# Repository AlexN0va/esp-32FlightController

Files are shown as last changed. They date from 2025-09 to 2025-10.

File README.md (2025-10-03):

# ESP32-S3 Drone Project 🚁

An ultra-compact, low-cost quadcopter platform powered by the **ESP32-S3 microcontroller**.
This project integrates **wireless control, power management, and a full sensing suite** into a **single PCB design**, achieving a robust and manufacturable drone for under **$50 per unit ($32.01)**.

---

##  Features

### Core Controller

* **ESP32-S3** microcontroller with **WiFi + Bluetooth** for remote control and telemetry.
* **USB-C** interface for programming and charging.
* **Status LEDs** for debugging and state indication.

### 📡 Wireless Control

* Built-in **WiFi/Bluetooth** communication.
* Custom real-time control protocol.

### Power Management

* **350mAh single-cell LiPo battery (1S)**.
* **Integrated charging circuitry** on PCB.
* **TPS5642 buck converter** regulates 3.7–4.2V battery input down to 3.3V.
* **Battery monitoring system** with undervoltage protection for safe operation.

### Motor Control

* **Four brushed DC motors** driven via **low RDS-on MOSFETs**.
* **PWM control** for smooth throttle response.
* Optimized **flyback diode placement** for reduced EMI and motor protection.

### Sensing Suite

* **BMP390 Barometer** – altitude measurements with ±0.5m accuracy.
* **ICM-42670-P 6-axis IMU** – accelerometer + gyroscope.
* **SPI communication** for fast and reliable sensor data exchange.
* **Sensor fusion algorithm** for stabilization.

### Compact Design

* **3.2” x 3.2” arms** with a **central PCB hub**.
* **Single-board design** for simplified manufacturing and assembly.
* **Integrated charging system** – no external circuitry required.

---

## Achieved Milestones

* Full system integration on a **single PCB**.
* Reliable flight stabilization using **sensor fusion**.
* Cost-effective design: **$32.01 BOM cost (under $50 target)**.

---

## Images 

### Final Drone Assembly & PCB Layout & Schematic

https://docs.google.com/presentation/d/1kFseCS2gQPJ-yQV6XV5w5bWRBxy75CzPxFKIJwM_sh4/edit?usp=sharing

---

## 📂 Repository Structure

```bash
├── firmware/          # ESP32-S3 firmware for flight control and wireless comm
├── hardware/          # PCB design files, schematics, layouts
├── docs/              # Images, diagrams, and documentation
└── README.md          # Project overview
```

---

## 🚀 Future Work

* Improve flight algorithms with advanced sensor fusion (Kalman filter / complementary filter).
* Add support for brushless motors + ESCs.
* Expand telemetry features (battery %, orientation, altitude streaming).
* Enhance custom wireless control protocol for lower latency.

---

Would you like me to also **add a wiring diagram block** (using ASCII art or schematic-style markdown) to visually show how the ESP32, sensors, power, and motors connect, so people can understand it even without opening the schematic files?

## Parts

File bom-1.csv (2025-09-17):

Designator | Footprint | Quantity | Value | LCSC Part #
3.3V | TestPoint_Loop_D1.80mm_Drill1.0mm_Beaded | 1 | +3.3V
BOOT, EN | SW_SKRPACE010 | 2 | SKRPACE010
C21, C23 | 0201 | 2 | 100nF
C22, C29 | 0201 | 2 | 10uF
C24 | 0201 | 1 | 10nF
C25, C31, C32, C4, C6, C7 | 0201 | 6 | 0.1uF
C26 | 0201 | 1 | 2.2uF
C27 | 0201 | 1 | 47uF
C28, C30 | 0201 | 2 | 1uF
C5 | 0201 | 1 | 22uF
CR1, CR2, CR3, CR4 | CFP3_SOD123W_NEX | 4 | PMEG10020ELRX
D1 | LED_Cree-PLCC4_3.2x2.8mm_CCW | 1 | CLV1L-FKB
D3 | SMF50AQTP | 1 | SMF5.0AQ-TP
D8 | 0603 | 1 | LED
IC2 | SOT50P160X60-6N | 1 | TPS564252DRLR
J7 | GCT_USB4105-GF-A | 1 | USB4105-GF-A
L2 | INDC2520X100N | 1 | 3.3uH
MOSFET1, MOSFET2, MOSFET3, MOSFET4 | SOT-23_MCC | 4 | SI2302-TP
MOTOR1 | Molex_CLIK-Mate_502382-0270_1x02-1MP_P1.25mm_Vertical | 1 | Motor1
MOTOR2 | Molex_CLIK-Mate_502382-0270_1x02-1MP_P1.25mm_Vertical | 1 | Motor2
MOTOR3 | Molex_CLIK-Mate_502382-0270_1x02-1MP_P1.25mm_Vertical | 1 | Motor3
MOTOR4 | Molex_CLIK-Mate_502382-0270_1x02-1MP_P1.25mm_Vertical | 1 | Motor4
MT1 | XDCR_ICM-42670-P | 1 | ICM-42670-P
R1, R13, R8 | 0201 | 3 | 120
R10, R11, R12, R19, R2, R21, R22, R6, R7, R9 | 0201 | 10 | 10k
R20 | 0201 | 1 | 45.3k
R23 | 0201 | 1 | 2k
R24 | 0201 | 1 | 13k
R25 | 0201 | 1 | 18k
R26, R27 | 0201 | 2 | 5k1
R3 | 0201 | 1 | 100k
R4 | 0201 | 1 | 50k
R5 | 0201 | 1 | 220R
TP3 | TestPoint_Loop_D1.80mm_Drill1.0mm_Beaded | 1 | GND
U1 | ESP32-S3-WROOM-1 | 1 | ESP32-S3-WROOM-1
U2 | SOT-666 | 1 | USBLC6-2P6
U4 | WSON10_DLH_TEX | 1 | BQ25185DLHR
U7 | 10LGA_2X2X0p75_BOS | 1 | BMP390
VBAT | CONN_S2B-PH-K-S_JST | 1 | S2B-PH-K-SLFSN
VBUS | TestPoint_Loop_D1.80mm_Drill1.0mm_Beaded | 1 | VBUS

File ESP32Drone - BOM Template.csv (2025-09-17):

Partner 1 Name:Richard Gomez | Partner 1 Email:20177421Rgomez@berkeley.edu | Partner 2 Name: Emmanuel Matute | Partner 2 Email: lemz4@berkeley.edu | Partner 3 Name: | Partner 3 Email:
Instructions
Fill in the cells with the YELLOW highlight. Do not edit red cells. WE WILL ADJUST THE MULTIPLIER TO ACCOUNT FOR MULTIPLE BOARDS, YOU SHOULD NOT. Fill out the Digi-Key part # OR the Mouser Part #, DO NOT fill out both. Choose the cheapest distributor that has the part in stock. If the part is not in stock by the time we order parts, there is a risk that we will not purchase it. For any approved Amazon or Adafruit parts, leave Digi-key and Mouser Part# columns blank like the example. For approved Amazon parts, put the ASIN (under the Product Information Section) for Manufacturer Part # in the format "Amazon - ##########". For approved Adafruit parts, put the Product ID for Manufacturer Part # in the format "Adafruit - ####". |  |  |  |  |  |  |  |  |  |  | Total Price for Project
 |  |  |  |  |  |  |  |  |  |  | #VALUE!
Qty (for 1 board) | Manufacturer Part # | Digi-key Part#/SKU | Mouser Part#/SKU | Price/unit ($) | Purchase URL | Reference Designator | Description (include component value if applicable) | Datasheet Link | Multiple | Total Qty | Total Price/part ($)
Sensors/Motor
4 | 739 | 36-739-ND |  | 0.28 | Link | rubber for 716
4 | 108990001 | 1597-1202-ND |  | 1.95 | Link | 716 Motors |  | Link |  | 4
1 | ICM-42670-P | 1428-ICM-42670-PCT-ND |  | 3.66 | Link | (Main Sensor) Accelerometer, Gyroscope, Temperature, 6 Axis Sensor |  | Link |  | 0 | 0
4 | SI2302-TP | SI2302-TPMSTR-ND |  | 0.45 | Link | N-Channel Mosfet |  | Link |  | 0 | 0
1 | BMP390 | 828-BMP390CT-ND |  | 3.15 | Link | Barometer ( Digital Pressure Sensor) |  | Link |  | 0 | 0
4 | PMEG10020ELRX | 1727-2396-2-ND |  | 0.26 | Link |  | flyback diode | Link |  | 0 | 0
1 | C0603C222K3RACTU | 399-C0603C222K3RACTUTR-ND |  | 0.1 | Link | 2.2 µFCeramic Capacitor X7R |  |  |  | 0 | 0
4 | RK73H1JTTD1002F | 2019-RK73H1JTTD1002FTR-ND |  | $0.10 | Link |  | Mosfet pull-downs 10k | Link |  | 0 | $0.00
1 | CC0603KRX7R8BB103 | 311-1360-2-ND |  | $0.10 | Link | 10nF capacitor
3 | CC0603KRX7R7BB104 | 311-1088-2-ND |  | $0.08 | Link |  | capacitor 100nF decoupling | Link
Power Section: |  |  |  |  |  |  |  |  |  | #VALUE! | #VALUE!
1 | TPS564252DRLR | 296-TPS564252DRLRTR-ND |  | $0.46 | Link |  | Buck converter | Link |  | 0 | $0.00
1 | 497-5026-2-ND | USBLC6-2P6 |  | $0.44 | Link |  | ESD protection for USB | Link |  | 0 | $0.00
1 | USB4105-GF-A | 2073-USB4105-GF-ATR-ND |  | $0.78 | Link |  | USB-C Receptacle | Link |  | 0 | $0.00
1 | SMF5.0AQ-TP | 353-SMF5.0AQ-TPTR-ND |  | $0.11 | Link |  | TVS protection for VBUS | Link |  | 0 | $0.00
2 | RK73H1JTTD1002F | 2019-RK73H1JTTD1002FTR-ND |  | $0.10 | Link |  | Feedback resistor 10k and PG indicator |  |  | 0 | $0.00
1 | RMCF0603FT45K3 | RMCF0603FT45K3TR-ND |  | $0.10 | Link |  | Feedback resistor 45.3k |  |  | 0 | $0.00
5 | CC0603KRX7R7BB104 | 311-1088-2-ND |  | $0.08 | Link |  | capacitor 100nF |  |  | 0 | $0.00
4 | CL10A106MP8NNNC | 1276-1871-2-ND |  | $0.09 | Link |  | cap 10uF |  |  | 0 | $0.00
1 | GRM188R60J476ME01D | 490-GRM188R60J476ME01DTR-ND |  | $0.36 | Link |  | cap 47uF |  |  | 0 | $0.00
2 | RC0603FR-075K1L | 311-5.10KHRTR-ND |  | $0.10 | Link |  | USB CC resistors 5.1k |  |  | 0 | $0.00
1 | SRP3212-3R3M | 118-SRP3212-3R3MTR-ND |  | $0.18 | Link |  | Inductor |  |  | 0 | $0.00
1 | RC0603FR-07210RL | 311-210HRCT-ND |  | $0.10 | Link |  | 210 ohm resistor
1 | LTST-C190GKT | 160-1183-2-ND |  | $0.14 | Link |  | green led | Link
Lipo-Charger
1 | BQ25185DLHR | 296-BQ25185DLHRTR-ND |  | $1.80 | Link |  | lipo batt. charger 1A | Link |  | 0 | $0.00
2 | CL10B105KA8NNNC | 1276-1184-2-ND |  | $0.06 | Link |  | 1uf cap |  |  | 0 | $0.00
1 | CL31B106KAHNNNE | 1276-1804-2-ND |  | $0.12 | Link |  | 10uf cap
3 | RK73H1JTTD1002F | 2019-RK73H1JTTD1002FTR-ND |  | $0.10 | Link |  | pullups/pulldowns | Link
1 | RK73H1JTTD1302F | 2019-RK73H1JTTD1302FTR-ND |  | $0.10 | Link |  | ILIM resistor 13k | Link
1 | AC0603FR-0718KL | YAG3570TR-ND |  | $0.10 | Link |  | ILIM resistor 18k | Link
1 | ERA-3AEB202V | P2.0KDBTR-ND |  | $0.10 | Link |  | 2k ISET resistor | Link
MCU: |  |  |  |  |  |  |  |  |  | #VALUE! | #VALUE!
 | ESP32-S3-WROOM-1-N8 | ESP32-S3-WROOM-1-N8 |  | 5.49 | Link |  | esp32 |  |  | 0 | 0
3 | CC0603KRX7R7BB104 | 311-1088-2-ND |  | $0.08 | Link |  | capacitor 100nF decoupling/switch debounce |  |  | 0 | $0.00
1 | CL10A226MP8NUNE | CL10A226MP8NUNE |  | $0.10 | Link |  | 22uF |  |  | 0 | $0.00
2 | SKRPACE010 | 4809-SKRPACE010TR-ND |  | $0.11 | Link |  | switch for en pin and boot |  |  | 0 | $0.00
1 | ERJ-3EKF1003V | P100KHTR-ND |  | $0.10 | Link |  | 100k for voltage sense |  |  | 0 | $0.00
1 | RT0603BRD0750KL | 13-RT0603BRD0750KLTR-ND |  | $0.14 | Link |  | 50k for voltage sense |  |  | 0 | $0.00
2 | RK73H1JTTD1002F | 2019-RK73H1JTTD1002FTR-ND |  | $0.10 | Link |  | 10k pullup for en and boot |  |  | 0 | $0.00
1 | CLV1L-FKB-CJ1N1E1BB7B3B3 | 90-CLV1L-FKB-CJ1N1E1BB7B3B3TR-ND |  | $0.43 | Link |  | debug LEDS, status indication etc |  |  | 0 | $0.00
3 | ERA-3AEB121V | P120DBTR-ND |  | $0.10 | Link |  | Led resistor 120ohm |  |  | 0 | $0.00
Battery |  |  |  |  |  |  |  |  |  | #VALUE! | #VALUE!
1 |  |  |  |  |  |  |  |  |  | 0 | 0

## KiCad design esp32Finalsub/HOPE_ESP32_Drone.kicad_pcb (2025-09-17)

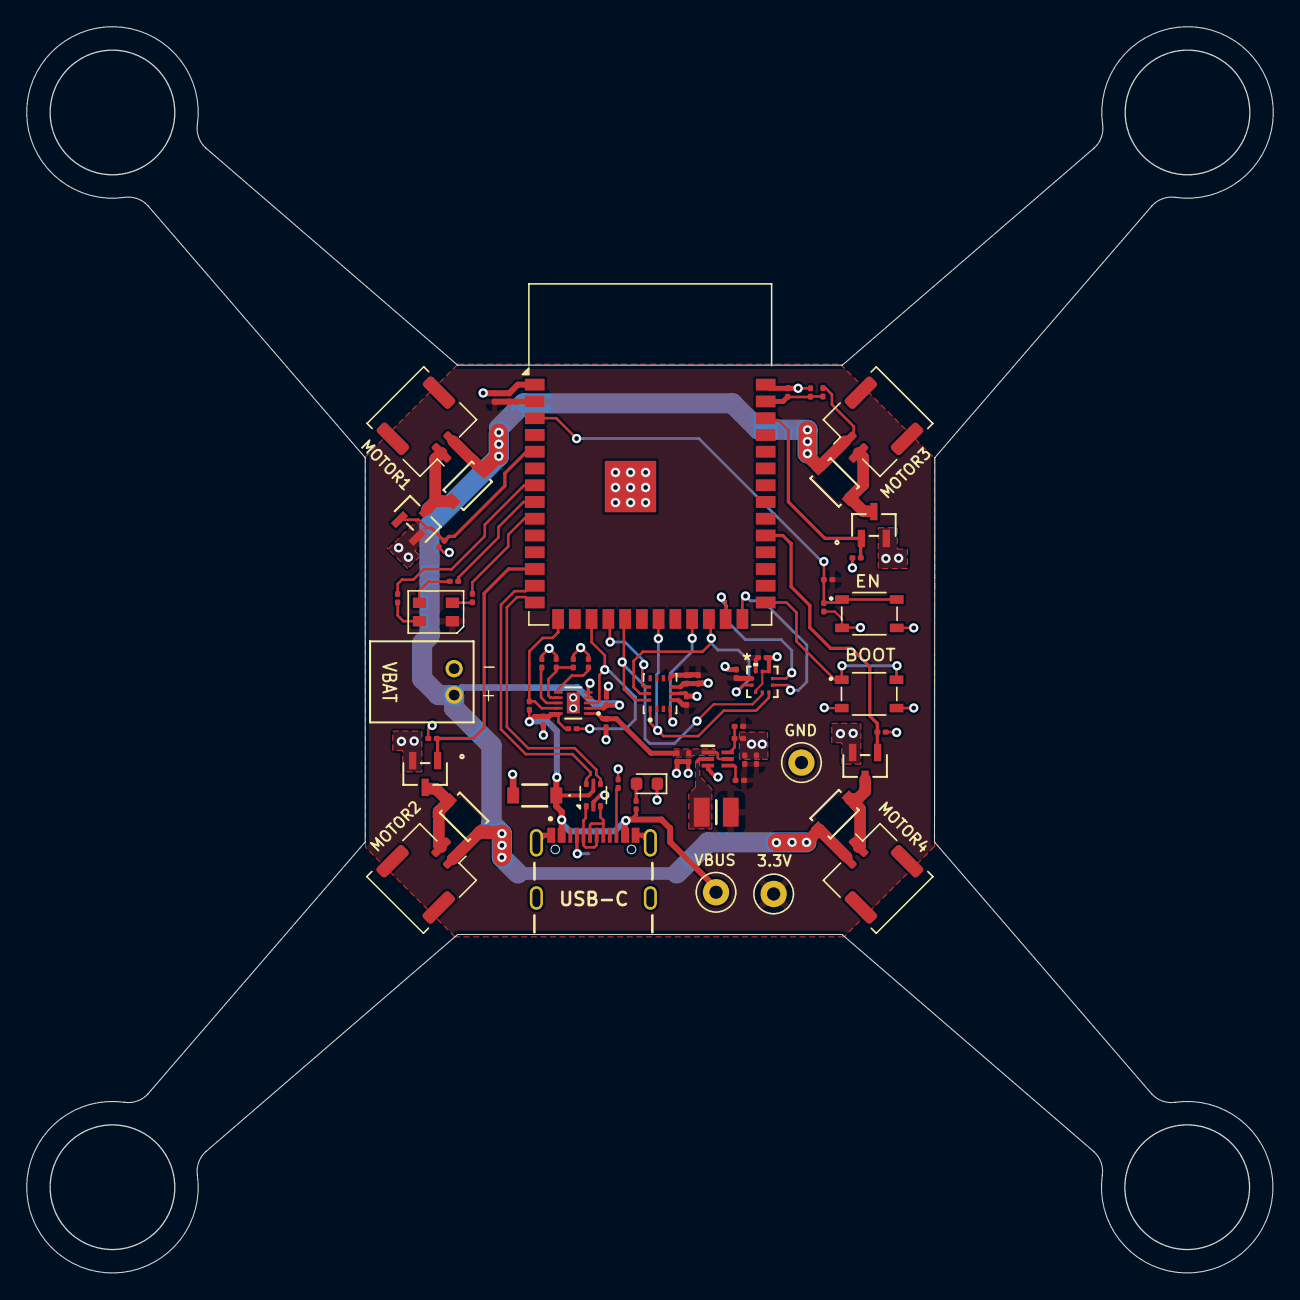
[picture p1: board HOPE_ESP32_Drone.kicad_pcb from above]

Board: 2 copper layers, 94.5 x 94.5 mm, 67 parts (1 on the bottom side), 44 nets.

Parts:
3.3V: +3.3V; TestPoint_Loop_D1.80mm_Drill1.0mm_Beaded
BOOT: SKRPACE010; SW_SKRPACE010
C4, C6, C7, C25, C31, C32: 0.1uF; C_0201_0603Metric
C5: 22uF; C_0201_0603Metric
C21, C23: 100nF; C_0201_0603Metric
C22, C29: 10uF; C_0201_0603Metric
C24: 10nF; C_0201_0603Metric
C26: 2.2uF; C_0201_0603Metric
C27: 47uF; C_0201_0603Metric
C28, C30: 1uF; C_0201_0603Metric
CR1, CR2, CR3, CR4: PMEG10020ELRX; CFP3_SOD123W_NEX
D1: CLV1L-FKB; LED_Cree-PLCC4_3.2x2.8mm_CCW
D3: SMF5.0AQ-TP; SMF50AQTP
D8: LED; LED_0603_1608Metric
EN: SKRPACE010; SW_SKRPACE010
IC2: TPS564252DRLR; SOT50P160X60-6N
J7: USB4105-GF-A; GCT_USB4105-GF-A
L2: 3.3uH; INDC2520X100N
MOSFET1, MOSFET2, MOSFET3, MOSFET4: SI2302-TP; SOT-23_MCC
MOTOR1: Motor1; Molex_CLIK-Mate_502382-0270_1x02-1MP_P1.25mm_Vertical
MOTOR2: Motor2; Molex_CLIK-Mate_502382-0270_1x02-1MP_P1.25mm_Vertical
MOTOR3: Motor3; Molex_CLIK-Mate_502382-0270_1x02-1MP_P1.25mm_Vertical
MOTOR4: Motor4; Molex_CLIK-Mate_502382-0270_1x02-1MP_P1.25mm_Vertical
MT1: ICM-42670-P; XDCR_ICM-42670-P
R1, R8, R13: 120; R_0201_0603Metric
R2, R6, R7, R9, R10, R11, R12, R19, R21, R22: 10k; R_0201_0603Metric
R3: 100k; R_0201_0603Metric
R4: 50k; R_0201_0603Metric
R5: 220R; R_0201_0603Metric
R20: 45.3k; R_0201_0603Metric
R23: 2k; R_0201_0603Metric
R24: 13k; R_0201_0603Metric
R25: 18k; R_0201_0603Metric
R26, R27: 5k1; R_0201_0603Metric
TP3: GND; TestPoint_Loop_D1.80mm_Drill1.0mm_Beaded
U1: ESP32-S3-WROOM-1
U2: USBLC6-2P6; SOT-666
U4: BQ25185DLHR; WSON10_DLH_TEX
U7: BMP390; 10LGA_2X2X0p75_BOS
VBAT: S2B-PH-K-SLFSN; CONN_S2B-PH-K-S_JST
VBUS: VBUS; TestPoint_Loop_D1.80mm_Drill1.0mm_Beaded

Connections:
+3.3V: 3.3V.1, C5.1, C6.1, C23.1, C24.1, C25.1, C26.1, C27.1, C31.1, C32.1, D1.1 (A), L2.2, MT1.5 (VDDIO), MT1.8 (VDD), R2.1, R19.2, R20.1, U1.2 (3V3), U7.1 (VDDIO), U7.10 (VDD)
+BATT: C28.1, CR1.1, CR2.1, CR3.1, CR4.1, MOTOR1.2, MOTOR2.1, MOTOR3.1, MOTOR4.2, R3.1, U4.2 (BAT), VBAT.2
/BMP_CS: U1.26 (IO45), U7.6 (CSB)
/BMP_INT: U1.25 (IO48), U7.7 (INT)
/D+: J7.A6 (DP1), J7.B6 (DP2), U2.3 (I/O2)
/D-: J7.A7 (DN1), J7.B7 (DN2), U2.1 (I/O1)
/DRIVER1: MOSFET1.1 (G), R9.1, U1.5 (IO5)
/DRIVER2: MOSFET2.1 (G), R10.1, U1.12 (IO8)
/DRIVER3: MOSFET3.1 (G), R11.1, U1.38 (IO2)
/DRIVER4: MOSFET4.1 (G), R12.1, U1.31 (IO38)
/ESP32-S3-WROOM/Boot: BOOT.1, BOOT.2, U1.27 (IO0)
/ESP32-S3-WROOM/EN: C4.1, EN.1, EN.2, R2.2, U1.3 (EN)
/ESP32-S3-WROOM/LED1: R1.1, U1.7 (IO7)
/ESP32-S3-WROOM/LED2: R8.1, U1.8 (IO15)
/ESP32-S3-WROOM/LED3: R13.1, U1.9 (IO16)
/ESP32-S3-WROOM/V_ADC: C7.1, R3.2, R4.1, U1.39 (IO1)
/IMU_CS: MT1.12 (AP_CS), U1.18 (IO10)
/IMU_INT: MT1.4 (INT1/INT), U1.23 (IO21)
/MISO: MT1.1 (AP_SDO/AP_AD0), U1.21 (IO13), U7.5 (SDO)
/MOSI: MT1.14 (AP_SDA/AP_SDIO/AP_SDI), U1.19 (IO11), U7.4 (SDI)
/Motor1-: CR1.2, MOSFET1.3 (D), MOTOR1.1
/Motor2-: CR2.2, MOSFET2.3 (D), MOTOR2.2
/Motor3-: CR4.2, MOSFET3.3 (D), MOTOR3.2
/Motor4-: CR3.2, MOSFET4.3 (D), MOTOR4.1
/REG: C21.1, C22.1, C29.1, IC2.1 (VIN), IC2.5 (EN), U4.1 (SYS)
/SCK: MT1.13 (AP_SCL/AP_SCLK), U1.24 (IO47), U7.2 (SCK)
/STAT1: R6.2, U1.15 (IO3), U4.9 (STAT1)
/STAT2: R7.2, U1.17 (IO9), U4.3 (STAT2)
/SW: IC2.2 (SW), L2.1
/USB+: U1.14 (USB_D+), U2.4 (I/O2)
/USB-: U1.13 (USB_D-), U2.6 (I/O1)
GND: BOOT.3, BOOT.4, C4.2, C5.2, C6.2, C7.2, C21.2, C22.2, C23.2, C24.2, C25.2, C26.2, C27.2, C28.2, C29.2, C30.2, C31.2, C32.2, D3.2 (A), D8.1 (K), EN.3, EN.4, IC2.3 (GND), J7.A1_B12 (GND), J7.B1_A12 (GND), J7.SH1 (SHELL_GND), J7.SH2 (SHELL_GND), J7.SH3 (SHELL_GND), J7.SH4 (SHELL_GND), MOSFET1.2 (S), MOSFET2.2 (S), MOSFET3.2 (S), MOSFET4.2 (S), MT1.6 (GND), MT1.7 (FSYNC), R4.2, R9.2, R10.2, R11.2, R12.2, R21.2, R22.2, R23.2, R24.2, R25.2, R26.2, R27.2, TP3.1, U1.1 (GND), U1.40 (GND), U1.41 (GND), U2.2 (GND), U4.4 (/CE), U4.5 (GND), U4.11 (EPAD), U7.3 (VSS), U7.8 (VSS), U7.9 (VSS), VBAT.1
unnamed: D1.4 (BK), R1.2
unnamed: D1.3 (GK), R8.2
unnamed: D1.2 (RK), R13.2
unnamed: D8.2 (A), R5.2
unnamed: IC2.6 (FB), R20.2, R21.1
unnamed: IC2.4 (PG), R19.1
unnamed: J7.A5 (CC1), R26.1
unnamed: J7.B5 (CC2), R27.1
unnamed: R24.1, R25.1, U4.7 (ILIM/VSET)
unnamed: R23.1, U4.8 (ISET)
unnamed: R22.1, U4.6 (TS/MR)
VBUS: C30.1, D3.1 (K), J7.A4_B9 (VBUS), J7.B4_A9 (VBUS), R5.1, R6.1, R7.1, U2.5 (VBUS), U4.10 (IN), VBUS.1
